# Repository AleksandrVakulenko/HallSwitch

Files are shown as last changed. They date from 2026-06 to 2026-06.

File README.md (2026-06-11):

# Analog commutator 4x4 for automation of Hall effect measurement.

**Русский:**  
Программно-аппаратный комплекс для управления аналоговым коммутатором 4×4, предназначенным для автоматизации измерений эффекта Холла по методу Ван-дер-Пау. Состоит из драйверов для MATLAB, Python и LabVIEW, а также конструкции печатной платы.

**English:**  
A software/hardware package for controlling a 4×4 analog switch matrix designed to automate Hall-effect measurements (Van der Pauw method). Includes MATLAB, Python and LabVIEW drivers, plus the PCB design of the relay matrix.

---
## Command Protocol / Протокол команд

#### SCPI Commands / SCPI команды

| Команда (Command) | Описание (Description) |
|---|---|
| `*IDN?` | Прибор возвращает идентификационную информацию (модель, прошивка).<br/>The device returns identification information (model, firmware). |
| `*RST`  | Программный сброс прибора в исходное состояние (все входы отключены).<br/>Software reset of the device to its initial state (all inputs disconnected). |

#### Команды управления коммутатором

Коммутатор соединяет четыре буквенных входа (A, B, C, D) с четырьмя числовыми входами (1, 2, 3, 4). Команда представляет собой строку из 4 символов, определяющую, какой буквенный (или цифровой) контакт подключён к каждой позиции.

1. **Команда буквенного порядка** — порядок букв соответствует порядку номерных входов (1-2-3-4).
2. **Команда цифрового порядка** — порядок цифр соответствует порядку буквенных входов (A-B-C-D).

- Все символы должны быть заглавными буквами (A, B, C, D) или цифрами (1, 2, 3, 4). Смешивание букв и цифр в одной команде запрещено.
- Один и тот же символ (кроме `X`) не должен повторяться в команде.
- Чтобы оставить вход неподключённым, используйте символ `X`.

#### Switch Matrix Commands

The switch matrix maps the four lettered inputs (A, B, C, D) to the four numbered inputs (1, 2, 3, 4). A command is a 4-character string that specifies which letter (or number) is connected to each position.  

1. **Letter-order command** — the order of letters corresponds to the order of numbered inputs (1-2-3-4).  
2. **Digit-order command** — the order of digits corresponds to the order of lettered inputs (A-B-C-D).  

- All characters must be uppercase letters (A, B, C, D) or digits (1, 2, 3, 4). Mixing letters and digits in one command is forbidden.  
- A symbol (except `X`) must not appear more than once in the command.  
- To leave an input disconnected, use the character `X`.  

**Example 1 / Пример 1**

Требуемое подключение коммутатора / Desired switch connection:
| Букв. вход (Letter) | Числ. вход (Number) |
|---|---|
| A | 3 |
| B | 4 |
| C | 2 |
| D | 1 |

Команда буквенного порядка (Letter-order command): `DCAB`  
Команда цифрового порядка (Digit-order command): `3421`

**Example 2 / Пример 2**

Требуемое подключение коммутатора / Desired switch connection:
| Букв. вход (Letter) | Числ. вход (Number) |
|---|---|
| A | X (отключён / disconnected) |
| B | 1 |
| C | X (отключён / disconnected) |
| D | 3 |

Команда буквенного порядка (Letter-order command): `BXDX`  
Команда цифрового порядка (Digit-order command): `X1X3`

---
## Software

### MATLAB R2021b

**Русский:**  
- **Зависимости:** класс `aDevice` из модуля [Automation devices module](https://github.com/AleksandrVakulenko/Automation_device_class) пакетного менеджера [Fern](https://github.com/AleksandrVakulenko/Fern).  
- **Использование:**  
  1. Установите Fern.  
  2. Каждый раз после запуска MATLAB выполните `Fern.load('aDevice')`.  
  3. Создайте объект устройства: `Box = Hall_box(COM_port);`  
  4. Отправляйте команды, например: `Box.set_relay('ABCD');`  
- **Примеры:** `Matlab/TEST/Test_01.m`, `Matlab/TEST/Test_02.m`

**English:**  
- **Dependencies:** `aDevice` class from the [Automation devices module](https://github.com/AleksandrVakulenko/Automation_device_class) of the [Fern](https://github.com/AleksandrVakulenko/Fern) package manager.  
- **Usage:**  
  1. Set up Fern.  
  2. Run `Fern.load('aDevice')` every time after starting MATLAB.  
  3. Create the device object: `Box = Hall_box(COM_port);`  
  4. Send commands, e.g.: `Box.set_relay('ABCD');`  
- **Examples:** `Matlab/TEST/Test_01.m`, `Matlab/TEST/Test_02.m`

### Python

**Русский:**  
- **Зависимости:** библиотека `pyserial`.  
- **Использование:**  
  1) Установите pyserial: `python3 -m pip install pyserial`  
  2) Импортируйте класс: `from Hall_box import HallBox`  
  3) Создайте объект: `box = HallBox(com_port)`  
  4) Выполняйте команды: `err_status, err_no, err_comment = box.set_relay('ABCD')`  
- **Примеры:** `Python/Test_02.py`

**English:**  
- **Dependencies:** `pyserial`.  
- **Usage:**  
  1. Install pyserial: `python3 -m pip install pyserial`  
  2. Import the class: `from Hall_box import HallBox`  
  3. Create the device: `box = HallBox(com_port)`  
  4. Execute commands: `err_status, err_no, err_comment = box.set_relay('ABCD')`  
- **Examples:** `Python/Test_02.py`

### LabVIEW 17 (64-bit)

**Русский:**  
- **Использование:**  
  1. Загрузите файлы библиотеки из папки `LabView` (выберите версию).  
  2. Инициализируйте соединение с помощью VI `Commutator_init`.  
  3. Отправляйте команды через VI `Commutator_query_CMD`.  
  4. Закрывайте соединение через VI `Commutator_close`.  
- **Пример:** `Demo_terminal.vi`

**English:**  
- **Usage:**  
  1. Download the library files from the `LabView` folder (select the appropriate version).  
  2. Initialize the connection using `Commutator_init.vi`.  
  3. Send commands with `Commutator_query_CMD.vi`.  
  4. Close the connection with `Commutator_close.vi`.  
- **Example:** `Demo_terminal.vi`

---

## Hardware (version A1.3)

### Gerber-file notation

Расширения Gerber-файлов, входящих в проект, и соответствующие слои печатной платы.
<br> (*Gerber file extensions included in the project and the corresponding PCB layers.*)

| Обозначение (Ext.) | Полное название (Full name) | Описание слоя (Layer description) |
|---|---|---|
| **GTO** | Gerber Top Overlay | Верхняя шелкография / маркировка (Top Silkscreen) |
| **GTS** | Gerber Top Solder mask | Верхняя паяльная маска (Top Solder Mask) |
| **GTL** | Gerber Top Layer | Верхний слой меди (Top Copper) |
| **GBL** | Gerber Bottom Layer | Нижний слой меди (Bottom Copper) |
| **GBS** | Gerber Bottom Solder mask | Нижняя паяльная маска (Bottom Solder Mask) |
| **GBO** | Gerber Bottom Overlay | Нижняя шелкография (Bottom Silkscreen) |
| **GKO** | Gerber Keep-Out | Контур платы и запретные зоны (Board Outline / Keep-Out) |
| **LXN** | Layer X (eXtra) Notes | Слой металлизированных и неметаллизированных отверстий (Plated & non-plated holes) |

### Фотографии устройства / Device assembly photos

<p align="center">
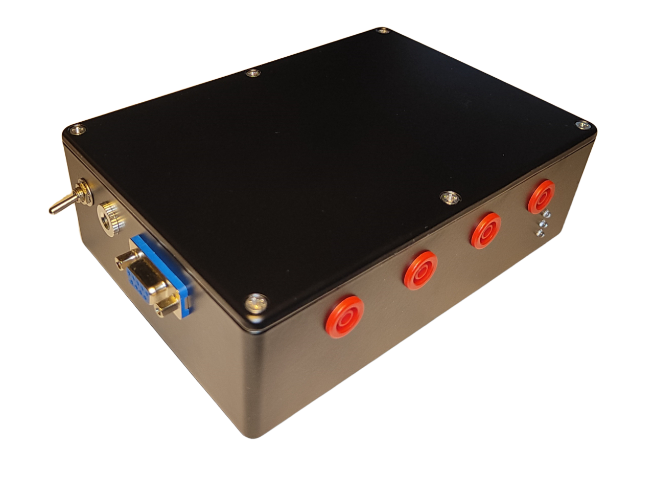
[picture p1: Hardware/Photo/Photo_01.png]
Общий вид спереди / Overview front
  
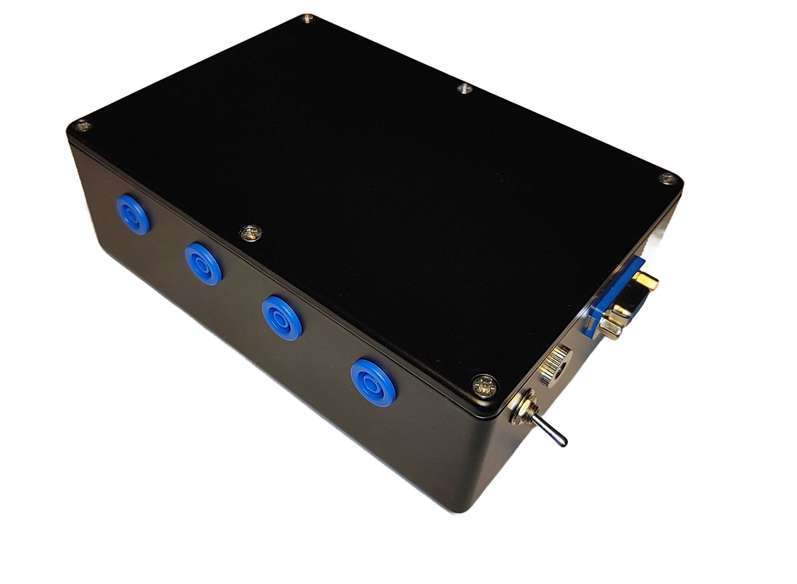
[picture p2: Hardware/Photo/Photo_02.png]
Общий вид сзади / Overview back
  
</p>
<p align="center">
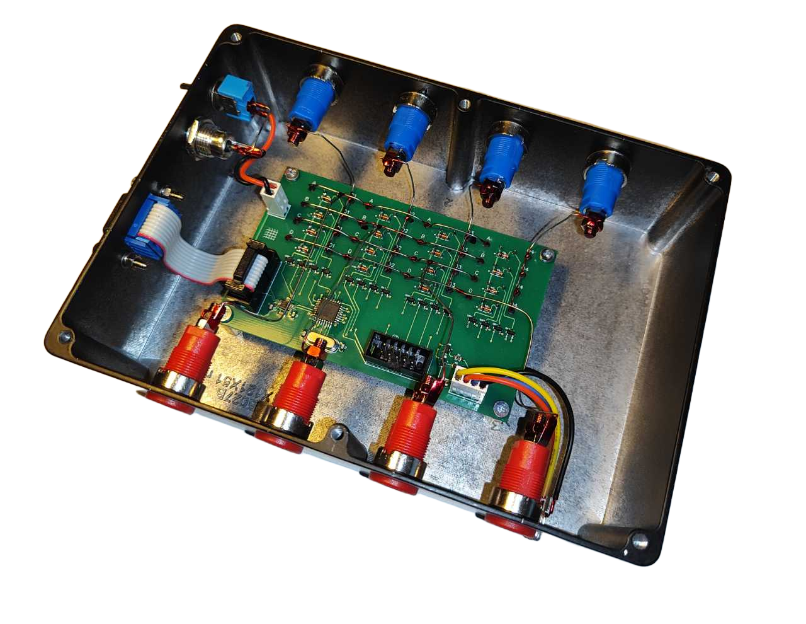
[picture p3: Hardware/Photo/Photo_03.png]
Общий вид внутри / Overview inside
  
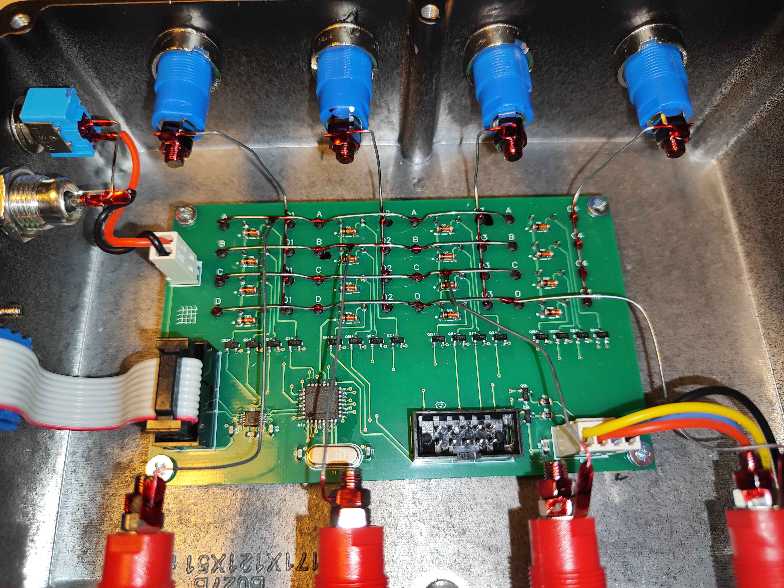
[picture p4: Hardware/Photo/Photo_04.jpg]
Монтаж платы / PCB assembly
  
</p>

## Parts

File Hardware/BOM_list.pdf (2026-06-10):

Designator | Description | Value | Package
C1, C2 | SMD Cap | 10 pF 50V | 0603
C3 – C6 | SMD Cap | 100 nF 16V | 0603
C7, C8 | SMD Cap | 10 uF 25V | 0603
D1 – D16 | SMD Diode | BAV103 | LL-34/SOD-80C
J1 | Socket | WF-4
J2 | Socket | WF-2
J4, J5 | Socket | IDC-10
Q1 – Q16, Q18, Q19 | SMD MOSFET | 2N7002 | SOT-23-3
R1 | SMD Resistor | 5.6 kOhm | 0603
R4 – R6 | SMD Resistor | 620 Ohm | 0805
SW1 – SW16 | Reed Relay | EDR101A0500 | SIP
U1 | CPU | AtMega328PB | TQFP-32
U2 | RS232-UART | ADM101EARMZ | MSOP-10
Y1 | XTAL | 20 MHz | HC-49S

Components J3, Q17, R2, R3 were missing during the design of version A1.3.

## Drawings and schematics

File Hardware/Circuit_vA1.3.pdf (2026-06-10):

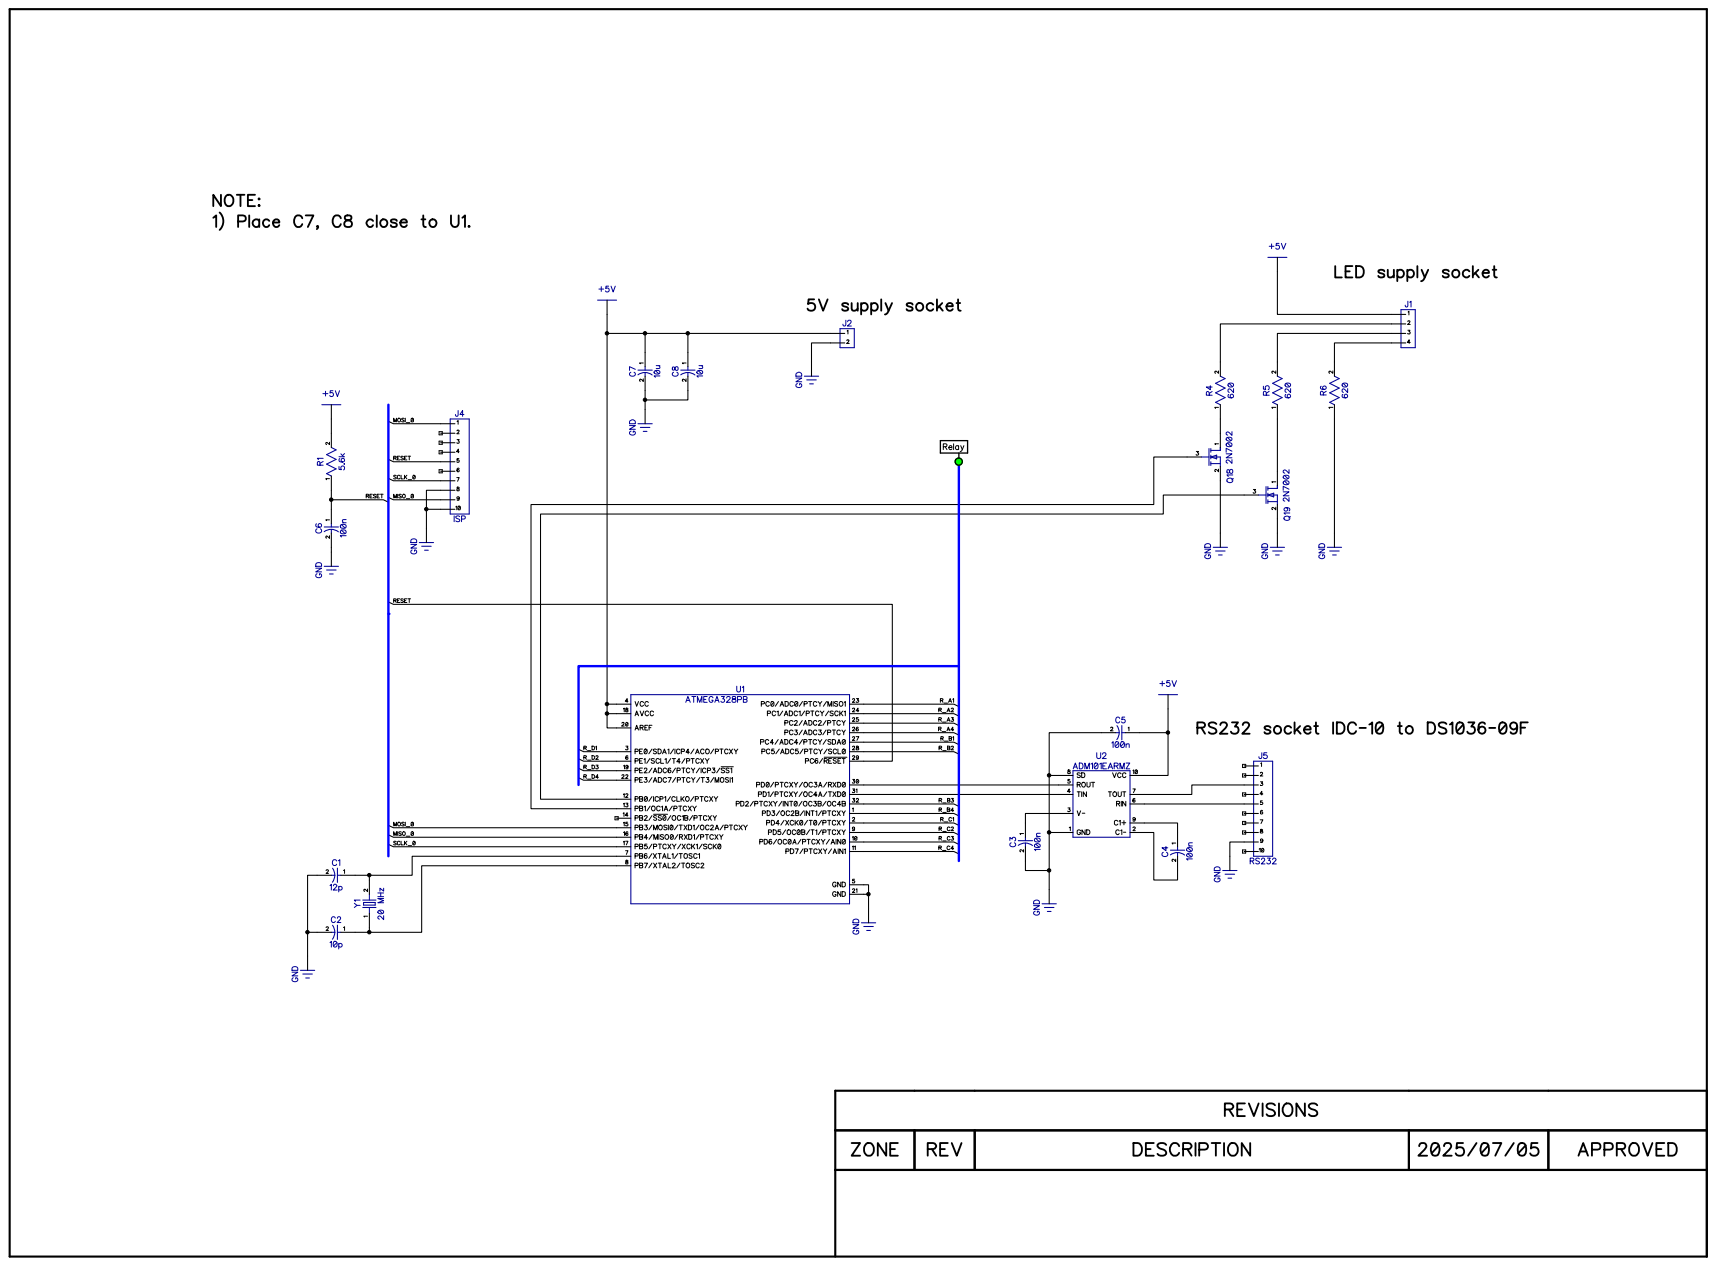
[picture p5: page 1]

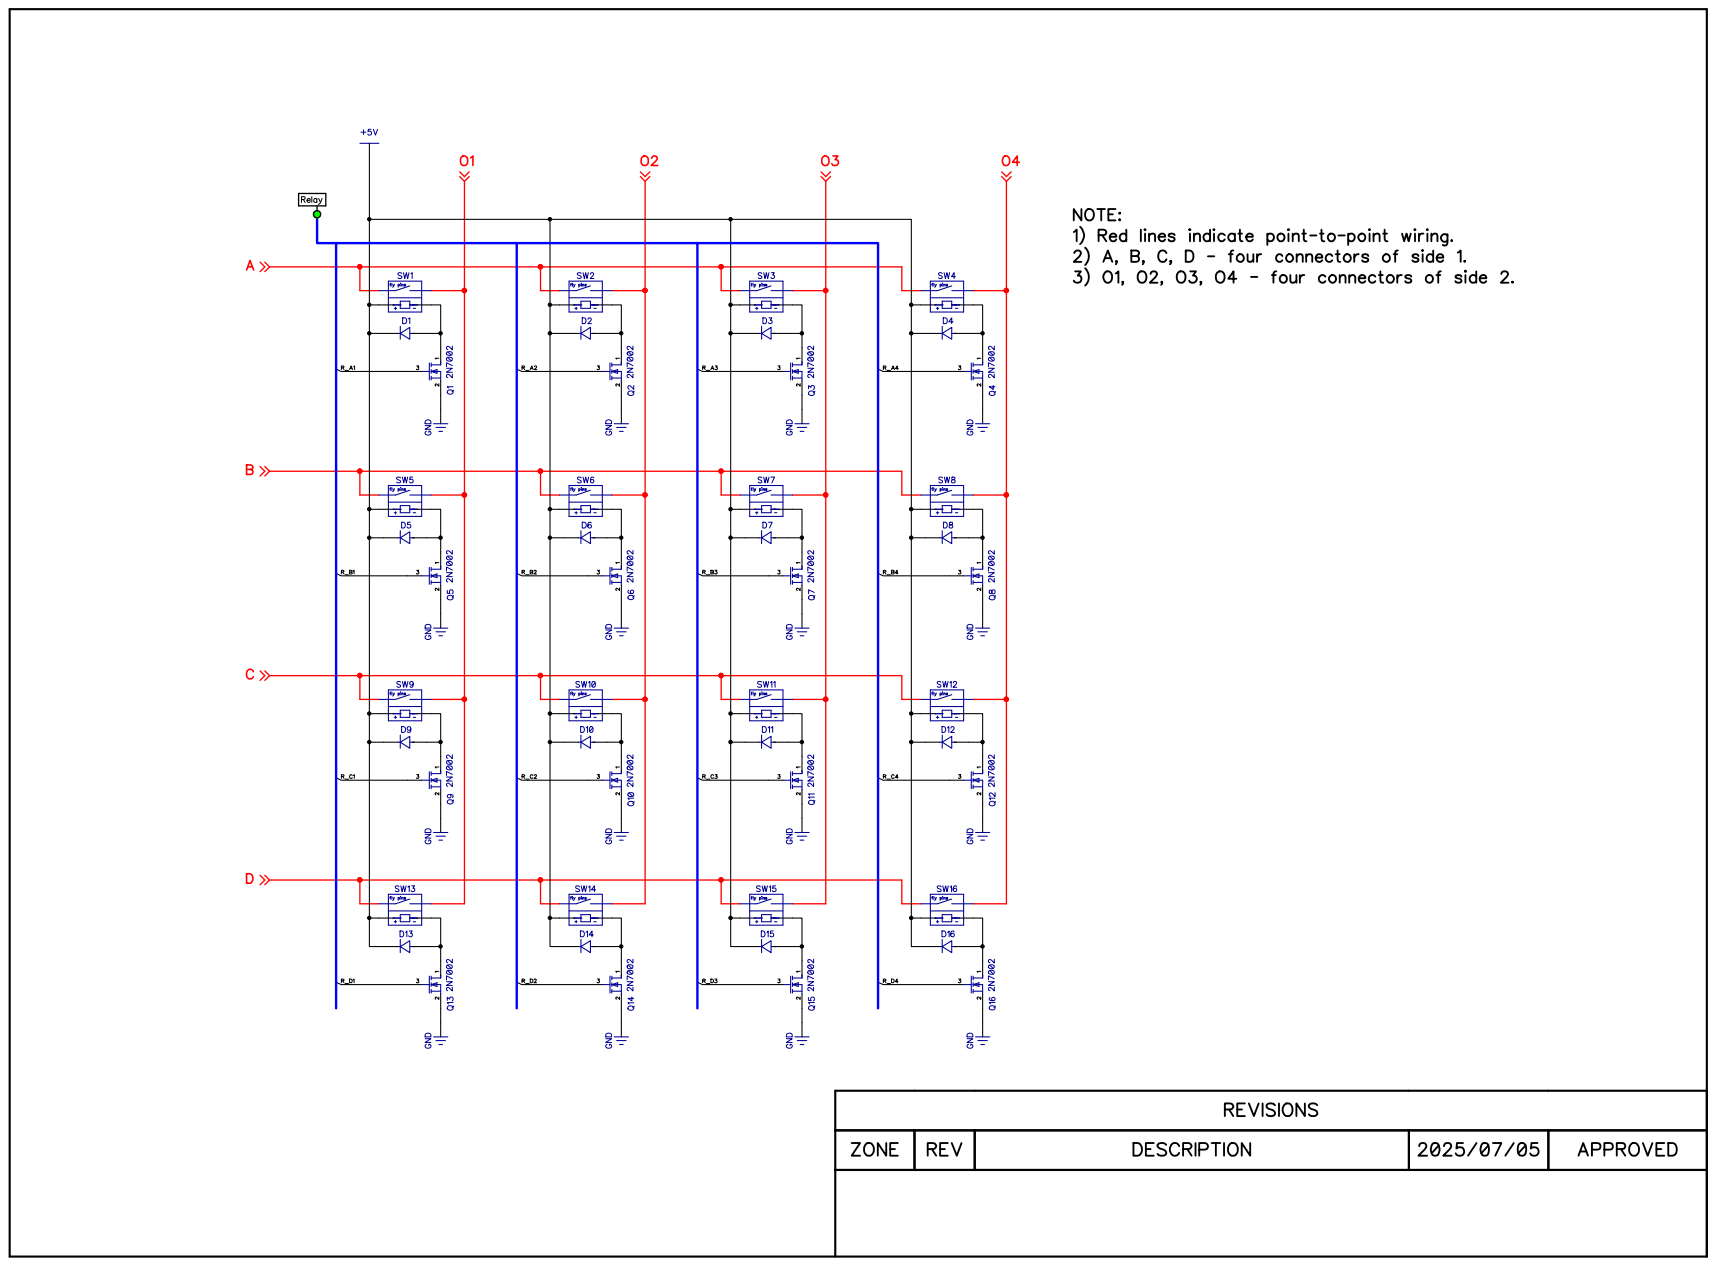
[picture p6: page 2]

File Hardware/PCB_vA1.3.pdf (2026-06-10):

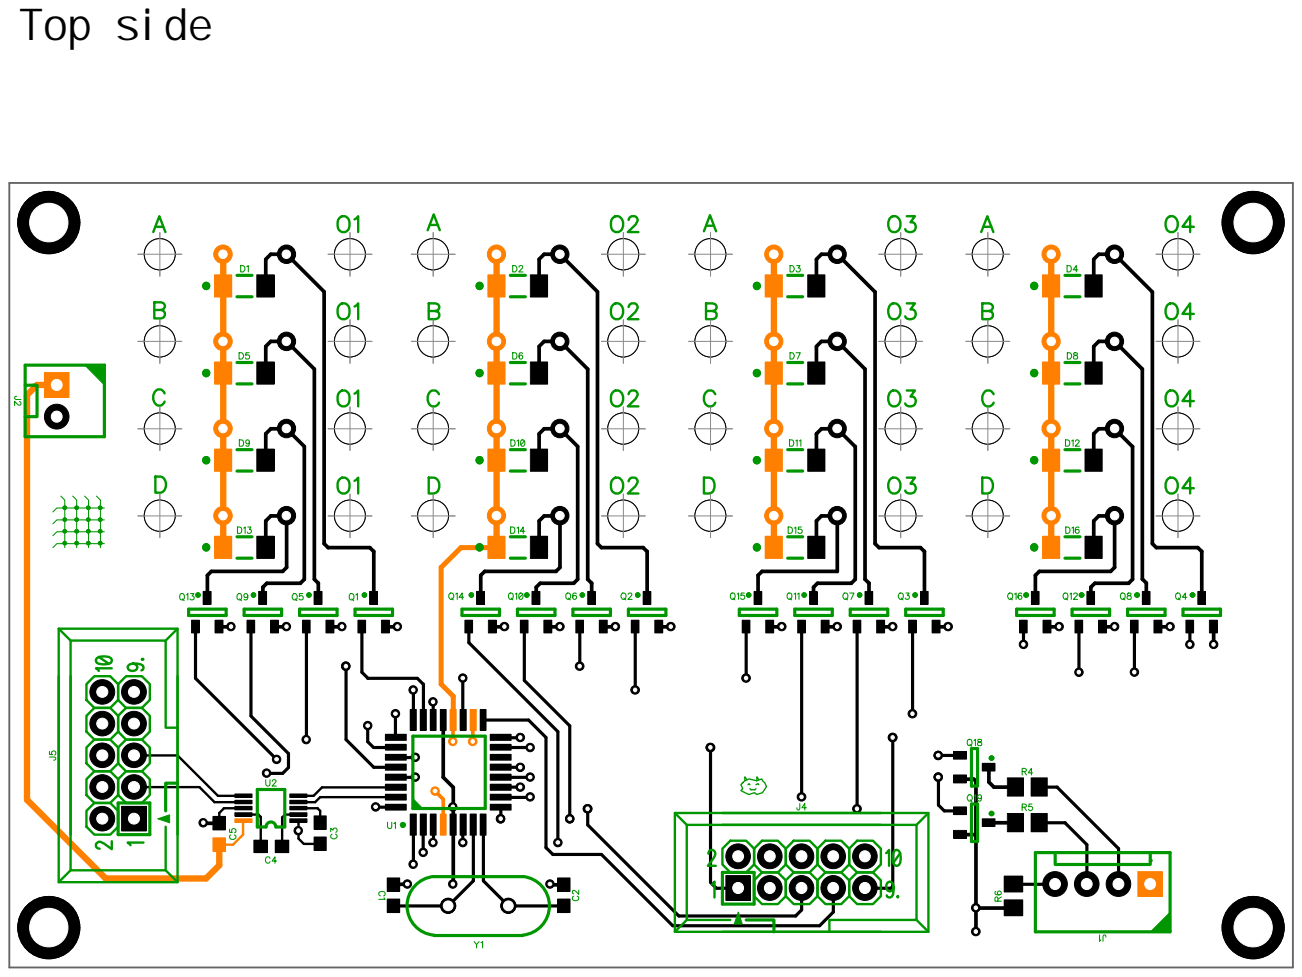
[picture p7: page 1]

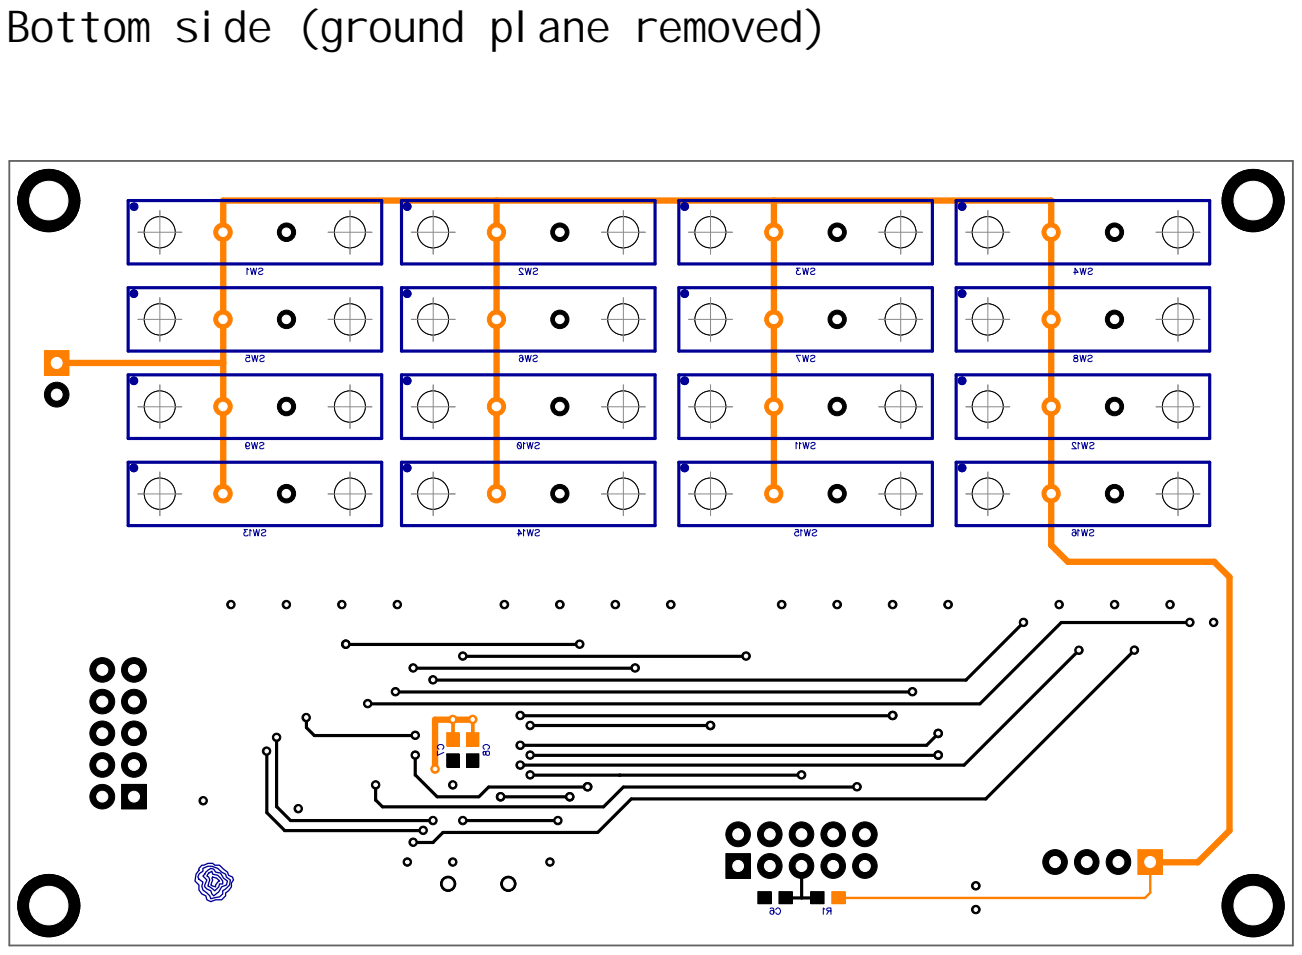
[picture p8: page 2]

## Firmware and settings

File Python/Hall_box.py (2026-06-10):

# Date: 2026.06.10
# Author: Aleksandr Vakulenko
# 
# This code was generated using DeepSeek and is an 
# automated translation of the corresponding 
# MATLAB R2021b code into Python.
# 
# Licensed after GNU GPL v3
# 

import serial
import time
from typing import Tuple, Optional

class HallBox:
    """
    Python translation of MATLAB Hall_box class.

    Replaces the aDevice base class and Connector_COM_RS232 with a
    standard pyserial Serial object. Retains original error parsing
    logic and command‑response protocol.
    """

    def __init__(self, com_port_num: int):
        """
        Parameters
        ----------
        com_port_num : int
            Non‑negative integer specifying the COM port number.
            E.g., 3 creates a connection to 'COM3'.
        """
        if not isinstance(com_port_num, int) or com_port_num < 0:
            raise ValueError("COM port number must be a non‑negative integer")
        self.port = f"COM{com_port_num}"
        # timeout chosen to allow the device time to answer;
        # adjust if your hardware requires a different value.
        self.ser = serial.Serial(port=self.port, baudrate=9600, timeout=1.0)

    # ------------------------------------------------------------------
    # Public methods (matching the original MATLAB interface)
    # ------------------------------------------------------------------
    def set_relay(self, cmd: str) -> Tuple[bool, Optional[int], Optional[str]]:
        """
        Send an arbitrary command and parse the response for errors.

        Parameters
        ----------
        cmd : str
            The command string (case insensitive).

        Returns
        -------
        err_status : bool
            True if the response indicates an error, False otherwise.
        err_no : int or None
            Error code extracted from the response (if any).
        err_comment : str or None
            Human‑readable description of the error (if any).
        """
        cmd_bytes = cmd.upper().encode('ascii') + b'\r'
        response = self._query(cmd_bytes)
        return self._error_parser(response)

    def idn(self) -> Tuple[str, bool, Optional[int], Optional[str]]:
        """
        Send the ``*IDN?`` identification command.

        Returns
        -------
        response : str
            Raw response string (error parsing is applied separately).
        err_status : bool
        err_no : int or None
        err_comment : str or None
        """
        cmd_bytes = b'*IDN?\r'
        response = self._query(cmd_bytes)
        err_status, err_no, err_comment = self._error_parser(response)
        return response, err_status, err_no, err_comment

    def rst(self) -> Tuple[bool, Optional[int], Optional[str]]:
        """
        Send the ``*RST`` reset command.

        Returns
        -------
        err_status : bool
        err_no : int or None
        err_comment : str or None
        """
        cmd_bytes = b'*RST\r'
        response = self._query(cmd_bytes)  # fix from original (response was undefined)
        return self._error_parser(response)

    # ------------------------------------------------------------------
    # Private helpers
    # ------------------------------------------------------------------
    def _query(self, cmd_bytes: bytes) -> str:
        """Write command, wait, read all available response bytes."""
        self.ser.write(cmd_bytes)
        time.sleep(0.1)                     # give device time to process
        if self.ser.in_waiting:
            response = self.ser.read(self.ser.in_waiting).decode('ascii', errors='ignore')
        else:
            response = ''
        # Strip any trailing whitespace / line terminators (the original
        # code used con_utils.discard_termination for the same purpose).
        return response.strip()

    @staticmethod
    def _error_parser(response: str) -> Tuple[bool, Optional[int], Optional[str]]:
        """
        Parse a response that may start with ``"RX ERROR: "``.

        Returns
        -------
        err_status, err_no, err_comment
            err_status is True if an error was found.
            err_no and err_comment are None when err_status is False.
        """
        err_no_list = [101, 102, 103, 200, 301, 302]
        err_comments_list = [
            'star cmd of size 4 is not an "*RST"',
            'star cmd of size 5 is not an "*IDN?"',
            "star cmd wrong size",
            "unknown cmd",
            "invalid symbol in cmd",
            "A symbol other than 'X' appeared twice."
        ]
        prefix = "RX ERROR: "
        n = len(prefix)

        if len(response) > n and response[:n] == prefix:
            err_status = True
            # Extract the error number that follows the prefix
            err_str = response[n:].strip()
            try:
                err_no = int(err_str)
            except ValueError:
                err_no = None

            if err_no in err_no_list:
                idx = err_no_list.index(err_no)
                err_comment = err_comments_list[idx]
            else:
                err_comment = "unknown error"
        else:
            err_status = False
            err_no = None
            err_comment = None

        return err_status, err_no, err_comment

    # ------------------------------------------------------------------
    # Cleanup
    # ------------------------------------------------------------------
    def close(self):
        """Explicitly close the serial port."""
        if self.ser.is_open:
            self.ser.close()

    def __del__(self):
        """Destructor – ensure the port is closed."""
        try:
            self.close()
        except Exception:
            pass

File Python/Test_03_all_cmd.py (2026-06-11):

# Date: 2026.06.10
# Author: Aleksandr Vakulenko
# 
# This code was generated using DeepSeek and is an 
# automated translation of the corresponding 
# MATLAB R2021b code into Python.
# 
# Licensed after GNU GPL v3
# 

import warnings
from Hall_box import HallBox      # класс из предыдущего ответа
from serial.tools import list_ports

def main():

    ports = [port.device for port in list_ports.comports()]
    print(ports)
    com_port = input("Enter COM port num: ");
    com_port = int(com_port)
    
    box = HallBox(com_port)

    # Таблица тестов: (команда, ожидаемый код ошибки или None, если ошибки не должно быть)
    test_table = [
        # Блок с перестановками букв A,B,C,D
        ("ABCD", None),
        ("ABDC", None),
        ("ACBD", None),
        ("ACDB", None),
        ("ADBC", None),
        ("ADCB", None),
        ("BACD", None),
        ("BADC", None),
        ("BCAD", None),
        ("BCDA", None),
        ("BDAC", None),
        ("BDCA", None),
        ("CABD", None),
        ("CADB", None),
        ("CBAD", None),
        ("CBDA", None),
        ("CDAB", None),
        ("CDBA", None),
        ("DABC", None),
        ("DACB", None),
        ("DBAC", None),
        ("DBCA", None),
        ("DCAB", None),
        ("DCBA", None),

        # Блок с цифрами 1,2,3,4
        ("1234", None),
        ("1243", None),
        ("1324", None),
        ("1342", None),
        ("1423", None),
        ("1432", None),
        ("2134", None),
        ("2143", None),
        ("2314", None),
        ("2341", None),
        ("2413", None),
        ("2431", None),
        ("3124", None),
        ("3142", None),
        ("3214", None),
        ("3241", None),
        ("3412", None),
        ("3421", None),
        ("4123", None),
        ("4132", None),
        ("4213", None),
        ("4231", None),
        ("4312", None),
        ("4321", None),

        # Один 'X' на каждой позиции
        ("XBCD", None),
        ("AXCD", None),
        ("ABXD", None),
        ("ABCX", None),

        # Два 'X'
        ("XXCD", None),
        ("XBXD", None),
        ("XBCX", None),
        ("AXXD", None),
        ("AXCX", None),
        ("ABXX", None),

        # Три 'X'
        ("XXXD", None),
        ("XXCX", None),
        ("XBXX", None),
        ("AXXX", None),

        # Четыре 'X'
        ("XXXX", None),

        # Комбинации цифр и X
        ("X234", None),
        ("1X34", None),
        ("12X4", None),
        ("123X", None),
        ("XX34", None),
        ("X2X4", None),
        ("X23X", None),
        ("1XX4", None),
        ("1X3X", None),
        ("12XX", None),
        ("XXX4", None),
        ("XX3X", None),
        ("X2XX", None),
        ("1XXX", None),
        ("XXXX", None),

        # Ошибка 301 – недопустимый символ (цифра или буква не A,B,C,D)
        ("1BCD", 301),
        ("2BDC", 301),
        ("3CBD", 301),
        ("4CDB", 301),
        ("A2BC", 301),
        ("AD12", 301),
        ("B4CD", 301),
        ("B3DC", 301),
        ("B212", 301),
        ("43AC", 301),
        ("BD2A", 301),

        # Ошибка 302 – символ повторяется (не 'X')
        ("2243", 302),
        ("3324", 302),
        ("4342", 302),
        ("1223", 302),
        ("1412", 302),
        ("2434", 302),
        ("2343", 302),
        ("2212", 302),
        ("4313", 302),
        ("2421", 302),
        # Спецсимволы / и . (также ошибка 301)
        ("//.*", 301),
        ("4317", 301),
        ("0223", 301),

        # Повторяющиеся буквы (302)
        ("CACD", 302),
        ("CADD", 302),
        ("ABAD", 302),
        ("CBBA", 302),
        ("CDCB", 302),
        ("CBBA", 302),
        ("DABA", 302),
        ("AACB", 302),
        ("DCAC", 302),
        ("DBBC", 302),

        # Повторяющиеся цифры (302)
        ("3134", 302),
        ("3144", 302),
        ("1214", 302),
        ("3221", 302),
        ("3411", 302),
        ("3221", 302),
        ("4121", 302),
        ("1132", 302),
        ("4313", 302),
        ("4223", 302),

        # Неправильная длина (200)
        ("A", 200),
        ("AB", 200),
        ("ABC", 200),
        ("CBCDE", 200),
        ("ABCDD", 200),
        ("", 200),
        ("rgddj", 200),

        # Неправильные звёздные команды (ошибки 103, 102, 101)
        ("*IDN??", 103),
        ("*", 103),
        ("*12", 103),
        ("*12345", 103),
        ("*1234567", 103),
        ("*1234", 102),
        ("*IDD?", 102),
        ("*    ", 102),
        ("*ABCD", 102),
        ("*123", 101),
        ("*RSS", 101),
        ("*   ", 101),
        ("*ABC", 101),
    ]

    n = len(test_table)
    status_arr = [False] * n
    results = []          # будет хранить (cmd, expected, got_err_no) для вывода в случае ошибок

    try:
        for i, (cmd, expected) in enumerate(test_table, start=1):
            print(f"{i}/{n} : {cmd}")
            _, err_no, _ = box.set_relay(cmd)

            # Формируем строковое представление для вывода (пусто -> [])
            err_no_str = str(err_no) if err_no is not None else '[]'
            exp_str = str(expected) if expected is not None else '[]'
            print(f"    <{err_no_str}> = <{exp_str}>")

            # Логика сравнения: оба пустые -> успех, иначе числовое совпадение
            if err_no is None and expected is None:
                status = True
            else:
                status = (err_no == expected)

            status_arr[i-1] = status
            results.append((cmd, expected, err_no))

            if status:
                print("    PASS")
            else:
                print("    FAIL")

    except Exception as e:
        box.close()
        warnings.warn('\nDevice is closed in error section')
        raise

    box.close()
    print('\nDevice is closed')

    # Итоговый отчёт
    if any(not s for s in status_arr):
        print("\nFailed tests:")
        for idx, (cmd, expected, got) in enumerate(results):
            if not status_arr[idx]:
                exp_str = str(expected) if expected is not None else '[]'
                got_str = str(got) if got is not None else '[]'
                print(f"  {cmd}  expected:{exp_str}  got:{got_str}")
    else:
        print("All tests passed.")

if __name__ == '__main__':
    main()

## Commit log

2026-06-10 add hardware part
    [Relay.GBL.gbr, Relay.GBO.gbr, Relay.GBS.gbr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]
2026-06-10 add device photos, update reamde draft
2026-06-10 update readme and pdf filr of hardware circuit
2026-06-10 add BOM list
